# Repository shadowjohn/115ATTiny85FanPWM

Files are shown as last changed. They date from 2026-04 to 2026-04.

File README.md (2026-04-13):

# 115ATTiny85FanPWM

使用 `ATTiny85` 產生約 `25kHz` PWM 訊號，控制 4 線式 12V 風扇的轉速。  
本專案透過 `PB4` 讀取 `10K VR` 可變電阻的類比值，再由 `PB1 / OC1A` 輸出 PWM，搭配外部電晶體電路驅動風扇的 PWM 腳位。

整個 repo 除了 Arduino 程式，還包含 Fritzing 電路圖、接線示意圖與自訂零件，可作為重做電路與後續修改的基礎。

---

## 功能特色
- 使用 `ATTiny85` 內建 Timer/PWM 輸出約 `25kHz` 控制訊號
- 使用 `10K VR` 旋鈕調整風扇轉速
- `PB4` 讀取 ADC，將 `0~1023` 映射為 `0~10` 共 11 段輸出
- `PB1 / OC1A` 輸出 PWM，適合 4 線式 PWM 風扇控制
- 提供 `7V~20V -> 5V` 穩壓參考電路
- 附 Fritzing 原始檔與自訂零件，可直接修改電路圖

---

## 作者
- 羽山秋人(https://3wa.tw)

---

## 日期
- 2026-04-14

---

## 材料清單
- `ATTiny85`
- `10K VR` 可變電阻
- `2N2222` (EBC)
- `TIP41C` (BCE)
- `TL431` (RAK)
- `560R` 電阻
- `1K` 電阻
- `10K` 電阻 x2
- `470uF / 50V` 電解電容
- 4 線式 PWM 風扇
- `12V~15V` 風扇電源，或依實際電路使用 `7V~20V` 輸入後轉 `5V`

---

## 檔案說明
- `115ATTiny85FanPWM.ino`
  - 主程式，負責 ADC 讀值、PWM 初始化與輸出占空比控制
- `circuit12to5.png`
  - `7V~20V` 輸入轉穩定 `5V` 的接線示意圖
- `circuit_PWM.png`
  - 完整 PWM 風扇控制接線示意圖
- `fritzing_parts/`
  - 本專案使用到的 Fritzing 自訂零件

---

## 程式與接腳說明
- `ATTiny85 Clock` 設定為 `Internal 16MHz`
- `PB4` 作為 ADC 輸入，接 `10K VR` 可變電阻
- `PB1 / OC1A` 作為 PWM 輸出腳位
- `PWM_TOP = 39`
  - 在目前設定下，PWM 頻率約為 `25kHz`
- 程式流程
  - 先初始化 ADC
  - 再初始化 Timer1 PWM 輸出
  - 持續讀取 `PB4` 的 ADC 值
  - 將 ADC `0~1023` 映射成 `0~10`
  - 再換算成 `OCR1A` 所需的輸出值

程式中 PWM 不是直接把風扇 duty 寫入輸出腳位，而是先算出風扇目標 duty，再因應外部 `2N2222` 反相電路，輸出相反的占空比：

```c
fanDuty = (uint32_t)level * PWM_TOP / 10;
outDuty = PWM_TOP - fanDuty;
OCR1A = outDuty;
```

如果旋鈕方向與你的習慣相反，可在主迴圈中啟用這行反向邏輯：

```c
// level10 = 10 - level10;
```

---

## 接線圖

### 1. 7V~20V 轉穩定 5V
這張圖是獨立的降壓/穩壓參考，用來提供 `ATTiny85` 與控制電路穩定的 `5V` 電源。

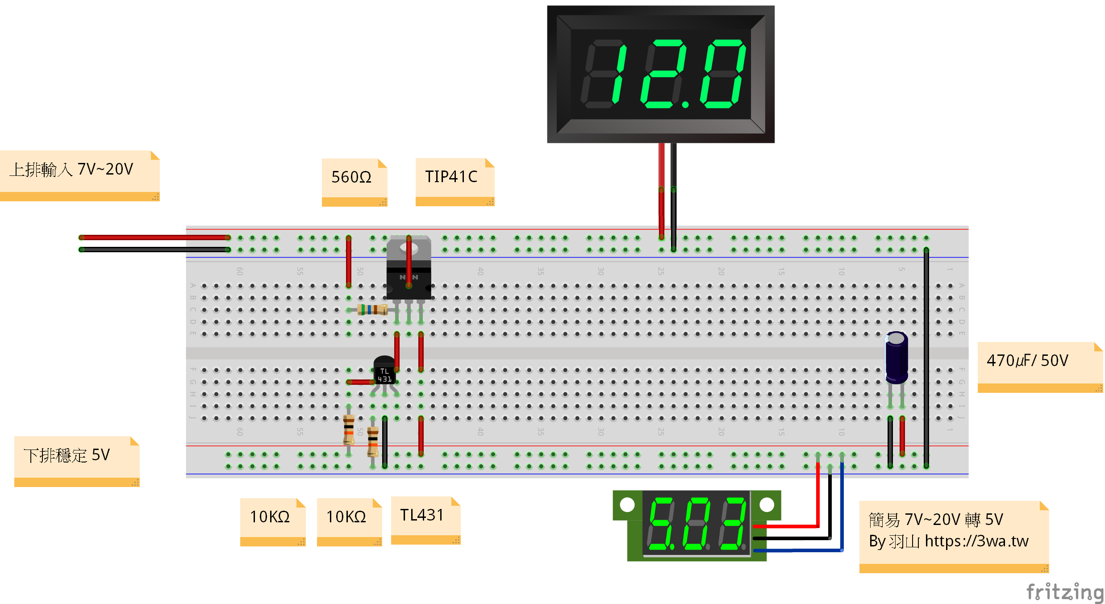
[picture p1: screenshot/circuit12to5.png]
7V~20V 轉 5V 穩壓電路


重點：
- 上排輸入為 `7V~20V`
- 下排輸出為穩定 `5V`
- 使用 `TL431`、`TIP41C` 與電阻組成簡易穩壓

### 2. PWM 風扇控制電路
這張圖是完整的風扇控制接線，包含 `ATTiny85`、可變電阻、PWM 輸出級與 4 線風扇。

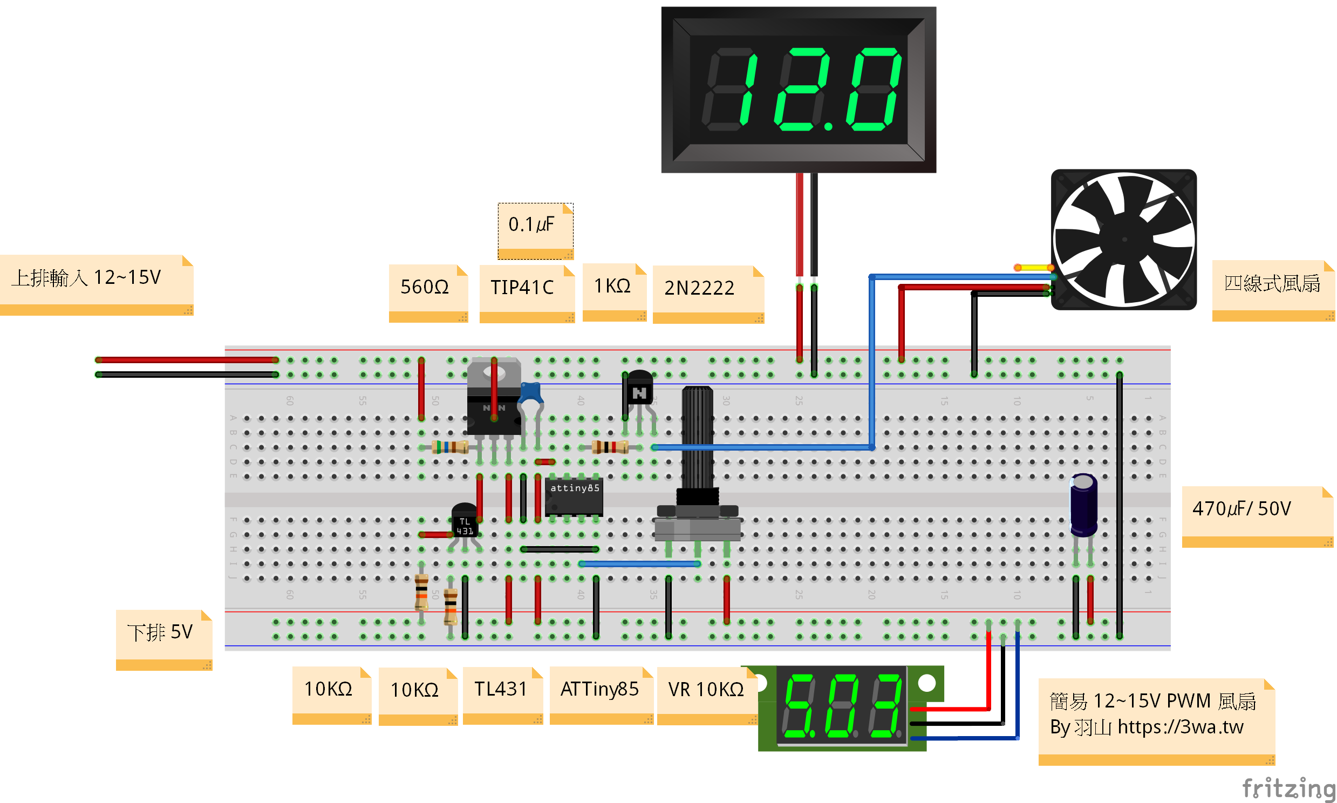
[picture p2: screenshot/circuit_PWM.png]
ATTiny85 PWM 風扇控制電路


重點：
- `PB4` 接 `10K VR`，用來調整速度
- `PB1` 經 `1K` 電阻送入 `2N2222` (EBC)
- `2N2222` 負責將 PWM 訊號反相後送往風扇 PWM 腳
- 風扇主電源仍由 `12V~15V` 供應，不是由 ATTiny85 直接供電
- `470uF / 50V` 電容用於電源穩定

---

## 燒錄與使用方式
1. 使用 Arduino IDE 或相容工具開啟 `115ATTiny85FanPWM.ino`
2. 確認目標晶片為 `ATTiny85`
3. 確認時脈設定為 `Internal 16MHz`
4. 將程式燒錄進晶片
5. 按照 `circuit_PWM.png` 接好電路
6. 上電後旋轉 `10K VR`，即可改變風扇 PWM 占空比與轉速

---

## 注意事項
- 這個專案控制的是 4 線風扇的 `PWM 控制腳`，不是直接切換風扇主電源
- 不同品牌或型號的 4 線風扇，PWM 相容性可能略有差異，請以實測為準
- 若風扇規格對 PWM 頻率有要求，請先確認是否接受約 `25kHz` 控制訊號
- 外部 `2N2222` 會造成訊號反相，因此程式內有做反向補償
- 若調整旋鈕後速度變化方向與預期相反，可啟用程式中的反向那一行
- 專案中的電路圖可作為實作參考，但實際配線、散熱與供電容量仍需依你的風扇規格調整

---

## 授權
MIT License

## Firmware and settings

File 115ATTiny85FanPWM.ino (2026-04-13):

/*
 115Attiny85FanPWM
 用於 FFB1212EH、PFC1212DE 控制藍腳 PWM 來讓風扇轉速改變
 可變電阻 PB4 10K 輸入
 控制輸出腳 PB1 頻率約為 25KHz，空佔比 0~100 (切10階)
 作者: 羽山秋人(https://3wa.tw)
 版本: V0.02
 ATTiny85 Clock: Internal 16MHz
 手冊 Spec: https://www.delta-fan.com/Download/Spec/PFC1212DE-F00.pdf
*/

#define F_CPU 16000000UL

#include <avr/io.h>
#include <util/delay.h>
#include <stdint.h>

#define PWM_TOP 39

static void adc_init(void)
{
    // Vref = Vcc, ADC2 = PB4
    ADMUX = (1 << MUX1);

    // ADC enable, prescaler = 64
    // 16MHz / 64 = 250kHz
    ADCSRA =
        (1 << ADEN)  |
        (1 << ADPS2) |
        (1 << ADPS1);
}

static uint16_t adc_read_once(void)
{
    ADCSRA |= (1 << ADSC);
    while (ADCSRA & (1 << ADSC));
    return ADC;   // 0~1023
}

static void pwm1_init_25khz_pb1(void)
{
    DDRB |= (1 << PB1);   // PB1 = OC1A output

    TCCR1 = 0;
    GTCCR = 0;

    OCR1C = PWM_TOP;
    OCR1A = PWM_TOP;   // 先關

    TCCR1 |= (1 << PWM1A);
    TCCR1 |= (1 << COM1A1);

    // CK/16 -> 約 25kHz
    TCCR1 |= (1 << CS12) | (1 << CS10);
}

static void pwm_set_level_10(uint8_t level)
{
    uint8_t fanDuty;
    uint8_t outDuty;

    if (level > 10) level = 10;

    // 0~10 直接映射到 0~39
    fanDuty = (uint32_t)level * PWM_TOP / 10;

    // 經 2N2222 反相
    outDuty = PWM_TOP - fanDuty;

    OCR1A = outDuty;
}

int main(void)
{
    uint16_t adcValue;
    uint8_t level10;

    adc_init();
    pwm1_init_25khz_pb1();

    while (1)
    {
        adcValue = adc_read_once();              // 0~1023
        level10 = (uint32_t)adcValue * 10 / 1023; // 0~10

        // 如果你的可變電阻轉向和你要的相反，
        // 就把下面這行取消註解：
        // level10 = 10 - level10;

        pwm_set_level_10(level10);

        _delay_ms(10);
    }
}

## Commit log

2026-04-13 更新專案
    [circuit.fzz, circuit12to5.fzz, circuit_PWM.fzz]
2026-04-13 更新 readme
